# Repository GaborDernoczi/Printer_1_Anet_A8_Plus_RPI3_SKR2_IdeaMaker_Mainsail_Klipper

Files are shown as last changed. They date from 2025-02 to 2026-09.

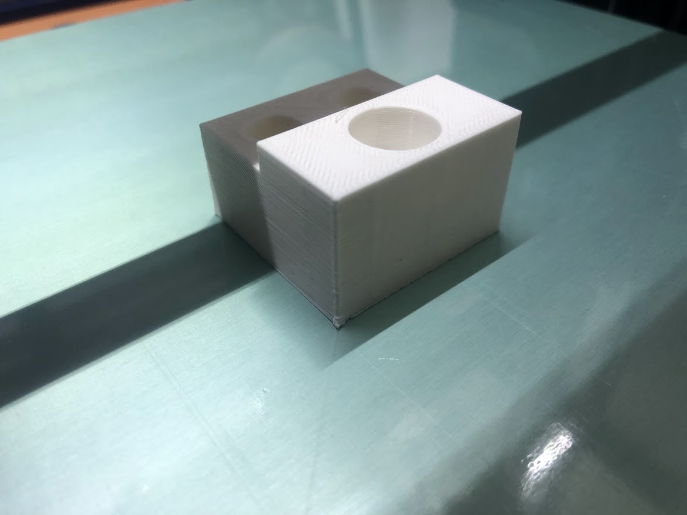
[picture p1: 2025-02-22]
Pictures/Test_Part_Print_1.jpg

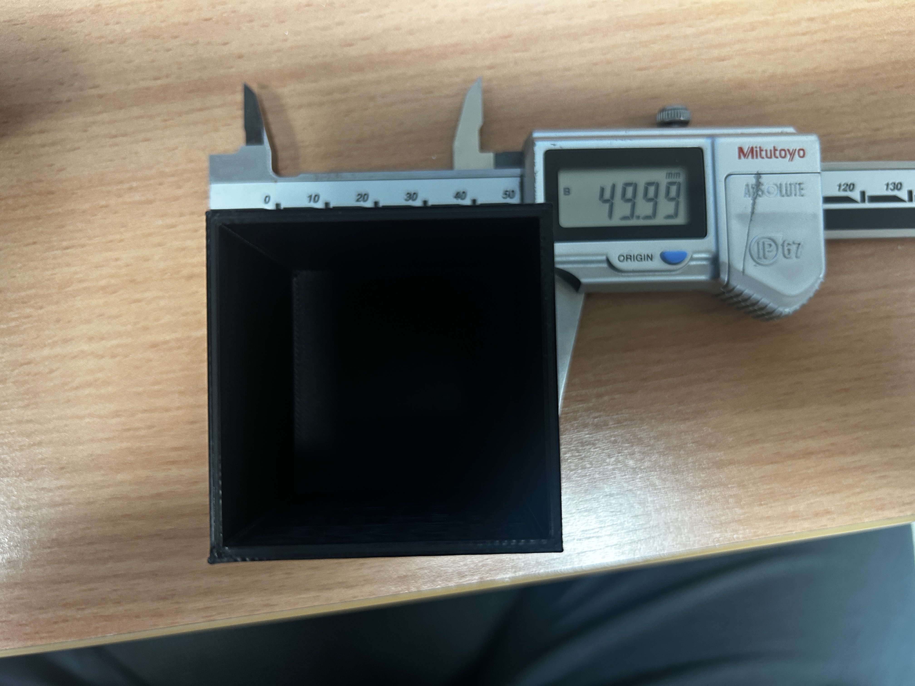
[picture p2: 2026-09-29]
Calibration_2.loop/IMG_4129.JPG

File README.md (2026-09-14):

# Printer #1 — Anet A8 Plus → Klipper / MainsailOS Conversion

> Converting an Anet A8 Plus from **Marlin + OctoPrint** to **Klipper + Mainsail**, running on a
> Raspberry Pi 3B+ with a BigTreeTech SKR 2 controller, sliced with the **latest version of
> IdeaMaker** — and fully operable remotely.

This repository is a complete build log and configuration archive. The goal is that the printer
can be **rebuilt from scratch using only the files in this repo**.

---

## Table of Contents

1. [Project Background](#1-project-background)
2. [System Architecture](#2-system-architecture)
3. [Remote Operation](#3-remote-operation)
4. [Hardware](#4-hardware)
5. [Repository Structure](#5-repository-structure)
6. [Rebuild Guide](#6-rebuild-guide)
7. [Key Configuration Values](#7-key-configuration-values)
8. [IdeaMaker Slicer Setup](#8-ideamaker-slicer-setup)
9. [Calibration Results](#9-calibration-results)
10. [Printed Upgrade Parts](#10-printed-upgrade-parts)
11. [References](#11-references)

---

## 1. Project Background

Printer #1 originally ran **Marlin firmware with OctoPrint**. It suffered from recurring problems:

- Inconsistent **bed adhesion**
- Unstable **temperature control**
- Poor and inconsistent print quality, leading to frequent failed prints
- Repeated bed-height calibration did not solve the underlying issues

Meanwhile, **Printer #2** had been running reliably for years on **Klipper + Mainsail**. Based on
that track record, the decision was made to migrate Printer #1 to the same platform.

The migration required separating the **IP addresses and Raspberry Pi hostnames** of the two
printers so both could coexist on the same network (two Raspberry Pis, two independent Mainsail
instances).

### Outcome

After the conversion the printer has been running **stably**, with no further adhesion or
temperature problems, and significantly improved print performance. Dimensional accuracy was then
dialled in through a documented calibration cycle (see section 9), and the whole workflow — from
slicing to starting the print — became operable without physically touching the machine
(see section 3).

---

## 2. System Architecture

```mermaid
flowchart LR
    PC["Workstation<br/>IdeaMaker slicer"]
    WEB["Browser<br/>Mainsail UI"]
    RPI["Raspberry Pi 3B+<br/>MainsailOS 64-bit<br/>hostname: pi1"]
    KLIPPY["Klippy host process<br/>+ Moonraker API"]
    SKR["BTT SKR 2<br/>STM32F407<br/>TMC2209 x4"]
    HW["Steppers · Heaters<br/>Thermistors · BLTouch"]

    PC -->|upload .gcode| WEB
    WEB -->|HTTP / WebSocket :7125| RPI
    RPI --- KLIPPY
    KLIPPY -->|USB serial| SKR
    SKR --> HW
```

**Division of labour:** the Raspberry Pi does all motion planning, kinematics, pressure advance
and bed-mesh compensation. The SKR 2 only executes pre-computed step timings. This is why the
Klipper configuration lives entirely in `printer.cfg` on the Pi, and the firmware on the board
almost never needs reflashing.

---

## 3. Remote Operation

A core goal of the conversion was **full remote control**: the entire chain — workstation, printer
power, slicing, print start and supervision — can be driven without being in the same room as the
machine.

```mermaid
flowchart TD
    U["Operator<br/>(remote / voice)"]
    ALEXA["Amazon Alexa"]
    SON["Sonoff 230 V smart socket"]
    NANO["Arduino Nano<br/>(powered from the socket, 5 V)"]
    REL["Relay module<br/>momentary contact closure"]
    BTN["PC front-panel<br/>PWR_SW header"]
    PCX["Workstation PC<br/>powers on"]
    PWR["Remote mains switch<br/>printer + Raspberry Pi"]
    PRN["Printer + Raspberry Pi<br/>power on"]
    SLICE["IdeaMaker<br/>slice + export G-code"]
    MS["Mainsail<br/>upload + start print"]
    CAM["Webcam via crowsnest<br/>live supervision"]

    U --> ALEXA --> SON --> NANO --> REL --> BTN --> PCX --> SLICE --> MS
    U --> PWR --> PRN --> MS
    MS --> CAM --> U
```

### Remote power-on of the workstation

The PC is **not** started with Wake-on-LAN. Instead it is started by physically pressing its own
power button, electrically:

1. The operator issues a switch-on command to **Amazon Alexa** (voice or app).
2. Alexa switches on a **Sonoff 230 V smart socket**.
3. The socket feeds an **Arduino Nano**, which therefore boots the moment mains power appears.
4. On start-up the Nano drives a **relay module**.
5. The relay **closes the contacts of the PC's power button** (the `PWR_SW` front-panel header),
   which boots the workstation.

The advantage over Wake-on-LAN is that it is completely independent of the BIOS, the network card,
the operating system and Windows fast-startup. It works even after a full power loss, because it
emulates the same physical action a person would perform.

> **Important:** the relay must produce a **short pulse (roughly 0.3–1 s), not a permanent
> closure.** A continuously held power button is interpreted by the PC as a forced shutdown
> request. The Nano sketch should therefore pulse the relay once after boot and then leave it
> open.

### What each piece does

| Capability | How | Result |
|---|---|---|
| **Start the PC remotely** | Alexa → Sonoff 230 V socket → Arduino Nano (5 V) → relay module → PC power-button contacts | The slicing machine is brought up on demand; no need to leave it running |
| **Start the printer remotely** | Remotely switchable mains power feeding the printer and the Pi | The machine stays powered down between jobs and is energised only when a print is planned |
| **Slice remotely** | Remote desktop onto the workstation, IdeaMaker running there | The slicer profile lives on one machine only — no profile drift |
| **Upload and start** | Mainsail web UI / Moonraker API on port 7125 | Upload `.gcode`, start, pause, cancel, tune live |
| **Watch the print** | `crowsnest` webcam stream embedded in Mainsail | Visual confirmation of the first layer and of progress |
| **Timelapse** | `moonraker-timelapse` (`timelapse.cfg`) | Automatic video of completed prints |

### Why the printer is kept unpowered between jobs

Leaving a heated-bed printer permanently energised is the main fire-risk scenario in a home
workshop. Putting the mains feed on a remotely switchable outlet makes the **default state "off"**,
and power is applied only for the duration of a supervised job. The Raspberry Pi boots in under a
minute, so there is no practical downside.

### Requirements and safety rules

- **Pulse, do not hold, the PC power button.** The Arduino Nano must close the relay only
  momentarily after boot; a permanently closed contact forces the PC off instead of on.
- **Use the relay contacts only as a dry switch** across the `PWR_SW` header. Never feed the
  Arduino's 5 V into the header — the relay must isolate the two circuits.
- **Set the PC BIOS "restore on AC power loss" option to "stay off"**, otherwise the machine may
  boot on its own and the relay pulse will shut it down again.
- **Give the Pi and the PC reserved DHCP leases** so their addresses never move.
- **Do not expose Mainsail or Moonraker directly to the internet.** Moonraker has no
  authentication model suitable for public exposure; `moonraker.conf` in this repo trusts private
  LAN ranges only. Reach the printer from outside over a **VPN**.
- **Never start a heater without a working camera view.** Remote power-on combined with an
  unattended thermal fault is precisely the combination to avoid.
- **Always verify the first layer on the camera** before leaving the print unattended.
- Keep a **physically reachable power cut-off**. A remote switch must never be the only way to
  de-energise the printer.

---

## 4. Hardware

| Component | Part | Notes |
|---|---|---|
| Base printer | Anet A8 Plus | 300 × 300 × 300 mm build volume |
| Frame | Reinforced aluminium-extrusion conversion | Diagonal bracing + corner gussets (AM8-style). Replaces the original acrylic frame. |
| Controller | BigTreeTech **SKR 2** | STM32F407 (verify — later batches use STM32F429) |
| Stepper drivers | **TMC2209** ×4 | UART mode |
| Host | **Raspberry Pi 3B+** | MainsailOS 64-bit |
| Hotend | **Volcano V6** | Custom mounting solution |
| Probe | **BLTouch / 3D Touch** | Automatic bed mesh levelling |
| Power | **External MOSFET** for the heated bed | Offloads bed current from the board |
| Mains control | **Remotely switchable outlet** (smart plug / relay) | Allows the printer to be powered up and down remotely — see section 3 |
| Camera | USB / Pi camera via **crowsnest** | Live view for remote supervision; timelapse support included |
| Slicer host | Workstation PC, started by the Sonoff + Arduino Nano + relay circuit | Runs the latest IdeaMaker; can be started remotely — see section 3 |
| PC remote start | **Sonoff 230 V smart socket** + **Arduino Nano** + **relay module** | Alexa-triggered; the relay shorts the PC power-button contacts |

> ⚠️ **Check your SKR 2 revision.** The initial revision of this board has a known flaw that can
> damage itself and other boards. Verify your board is not affected before powering it up.

---

## 5. Repository Structure

| Path | Contents |
|---|---|
| `Configuration_Files_Mainsail_Klipper/` | `printer.cfg`, `moonraker.conf`, `mainsail.cfg`, `crowsnest.conf`, `sonar.conf`, `timelapse.cfg` — the full working Klipper/Moonraker config set |
| `Calibration/` | Calibration log in **English** and **Hungarian**, test photos, IdeaMaker profile PDF, flow-calibration cube G-code |
| `IdeaMaker_Profiles/` | Slicer **Start G Code** and **End G Code** |
| `IdeaMaker_Models/` | `.idea` project files and `.3mf` models actually printed on this machine |
| `Consoles_and_Parts/` | STL files for printed upgrade parts (belt tensioners, fan duct, Pi case, spacers) |
| `Pictures/` | Build and diagnostic photos (BLTouch wiring, external MOSFET, printer render, test prints) |
| `SKR2_User manual/` | BigTreeTech SKR 2 pinout PDF |
| `Mainsail and Klipper Anet A8 Plus_RPI3_SKR2.pdf` | Step-by-step conversion presentation (also `.pptx`) |

---

## 6. Rebuild Guide

### Step 1 — Flash MainsailOS onto the SD card

1. Install **Raspberry Pi Imager**.
2. Choose **Other specific-purpose OS → 3D printing → MainsailOS (64-bit)**.
3. In the Imager's advanced settings, configure **before** writing:
   - **Hostname** — must be unique per printer (this build uses `pi1`)
   - **Wi-Fi SSID + password**
   - **SSH enabled**, username and password
4. Write the image and boot the Pi.

> **Running two printers?** Give each Pi a distinct hostname *and* a reserved (static) DHCP lease
> in the router. Two Pis = two independent Mainsail instances. Mixing them up is the most common
> cause of "I edited the config and nothing changed".

### Step 2 — Build the Klipper firmware for the SKR 2

SSH into the Pi (e.g. with **Tera Term** or any SSH client) and run:

```bash
cd ~/klipper
make menuconfig
```

Select:

| Option | Value |
|---|---|
| Micro-controller Architecture | `STMicroelectronics STM32` |
| Processor model | `STM32F407` *(use `STM32F429` if that is the chip on your board)* |
| Bootloader offset | `32KiB bootloader` |
| Communication interface | `USB (on PA11/PA12)` |

Then build:

```bash
make clean
make
```

The output is `~/klipper/out/klipper.bin`.

### Step 3 — Flash the board

`make flash` **does not work** on the SKR 2. Flash via SD card instead:

1. Download `out/klipper.bin` from the Pi (e.g. with **FileZilla** over SFTP).
2. Rename it to **`firmware.bin`**.
3. Copy it to a FAT32 SD card and insert it into the SKR 2.
4. Make sure the SKR 2 **power-source jumper is set correctly (5 V mode)**.
5. Power-cycle the board.
6. **Verification:** the file on the SD card is renamed to `firmware.cur`. If it still says
   `firmware.bin`, the flash did not happen — check the card format, the filename and the jumper.

### Step 4 — Find the MCU serial ID

On the Pi:

```bash
ls /dev/serial/by-id/*
```

Copy the returned path into the `[mcu]` section of `printer.cfg`. Example from this build:

```ini
[mcu]
serial: /dev/serial/by-id/usb-Klipper_stm32f407xx_2D0027000C47393437303337-if00
```

> This ID is **unique to your board** — it will not match the value in this repo. You must
> replace it.

### Step 5 — Upload the configuration

Copy `Configuration_Files_Mainsail_Klipper/printer.cfg` to the Pi, either through the Mainsail
web UI (**Machine** tab) or over SFTP to `~/printer_data/config/`.

Then check `moonraker.conf` — the `[authorization] trusted_clients` list must include your LAN
subnet, otherwise the web UI will refuse the connection.

Restart Klipper from Mainsail (`FIRMWARE_RESTART`).

### Step 6 — Wire and enable the BLTouch

Wiring photos: `Pictures/3d_touch.jpg`, `3d_touch_2.jpg`, `3d_touch_pins.jpg`.

The probe replaces the Z endstop — note that `[stepper_z]` uses
`endstop_pin: probe:z_virtual_endstop`.

### Step 7 — Safety checks before the first print

Run these **in order**, and keep a hand on the power switch:

```gcode
# 1. Thermistors read plausible room temperature?      -> check Mainsail dashboard
# 2. Does the probe deploy/stow?
BLTOUCH_DEBUG COMMAND=pin_down
BLTOUCH_DEBUG COMMAND=pin_up
# 3. Do the axes move the RIGHT way and hit the endstops?
G28
# 4. PID tuning
PID_CALIBRATE HEATER=extruder TARGET=200
PID_CALIBRATE HEATER=heater_bed TARGET=60
SAVE_CONFIG
# 5. Probe Z offset
PROBE_CALIBRATE
SAVE_CONFIG
# 6. Bed mesh
G28
BED_MESH_CALIBRATE
SAVE_CONFIG
```

> `SAVE_CONFIG` **restarts Klipper** — that is normal. It writes results into the auto-generated
> block at the bottom of `printer.cfg`, which **overrides** the values at the top of the file.

### Step 8 — Calibrate the extruder

Mark 120 mm of filament, then extrude 100 mm and measure what is left. `printer.cfg` already
contains `max_extrude_only_distance: 150` specifically to allow the 100 mm test (the Klipper
default of 50 mm is too small).

---

## 7. Key Configuration Values

From `Configuration_Files_Mainsail_Klipper/printer.cfg`:

### Motion

| Setting | Value | Why |
|---|---|---|
| `kinematics` | `cartesian` | |
| `stepper_x` / `stepper_y` `rotation_distance` | **40** | Theoretical value for a 16-tooth GT2 pulley — **do not change** |
| `stepper_z` `rotation_distance` | **8** | TR8×8 lead screw, mathematically exact — **never change** |
| `microsteps` | 16 (all axes) | |
| `position_max` X / Y / Z | 300 / 300 / 300 | |
| `max_velocity` | 300 mm/s | |
| `max_accel` | **1500** mm/s² | Reduced from 3000 to suppress ringing and corner defects |
| `square_corner_velocity` | 5.0 | |
| `max_z_velocity` / `max_z_accel` | 5 / 100 | |

### Extruder

| Setting | Value |
|---|---|
| `rotation_distance` | 35.845 (calibrated) |
| `nozzle_diameter` | 0.400 mm |
| `sensor_type` | EPCOS 100K B57560G104F |
| `max_temp` | 250 °C |
| `max_extrude_only_distance` | 150 mm |
| `pressure_advance` | 0.05 |
| `pressure_advance_smooth_time` | 0.040 |
| TMC2209 `run_current` | 0.600 A |

### Bed & Probe

| Setting | Value |
|---|---|
| `heater_bed` `sensor_type` | Generic 3950 |
| BLTouch `x_offset` / `y_offset` | **−30 / −25** |
| BLTouch `z_offset` | 1.25 |
| `samples` / `samples_result` | 2 / average |
| `safe_z_home` `home_xy_position` | 150, 150 (bed centre) |
| `bed_mesh` area | 35,30 → 280,280 |
| `bed_mesh` `probe_count` | 5 × 5, bicubic |
| XY/Z TMC2209 `run_current` | 0.800 A |

### SKR 2 specifics

```ini
# BTT implements a Marlin-specific "anti-reversal stepper protection".
# This pin MUST be pulled high or the stepper drivers and most FETs get no power.
[output_pin motor_power]
pin: PC13
value: 1
```

Forgetting this block is the classic "motors do nothing and there is no error message" failure on
the SKR 2.

---

## 8. IdeaMaker Slicer Setup

The slicer belonging to this printer is **IdeaMaker, latest version** (Raise3D). It is free, and
the profile stored in this repository is maintained against the current release — download it from
<https://www.raise3d.com/ideamaker/>.

Copy the contents of `IdeaMaker_Profiles/` into the printer definition in IdeaMaker.

**Start G-code** — homes all axes, moves to a bed-edge reference point, sets the coordinate zero
and performs a slow Z touch-off before lifting and priming.

**End G-code** — turns off both heaters, retracts in two stages while lifting Z, and disables the
steppers.

**Acceleration and Jerk are deliberately disabled in the slicer.** Klipper handles motion planning
itself, and letting the slicer inject `M204`/`M205` would fight the `max_accel` and
`square_corner_velocity` settings in `printer.cfg`.

The full profile is documented as screenshots in
`Calibration/Printer1_ANET_A8_Plus_RPI3_SKR2_Ideamaker_Current_Profile.pdf`.

---

## 9. Calibration Results

Test object: **50 × 50 × 50 mm** calibration cube. Full narrative in
[Calibration/Calibration_log_EN.txt](Calibration/Calibration_log_EN.txt) (Hungarian version:
[Kalibracios_naplo_HU.txt](Calibration/Kalibracios_naplo_HU.txt)).

| Test | X (mm) | Y (mm) | Z (mm) | Key settings |
|---|---|---|---|---|
| #1 | 48.63 (−1.37) | 49.76 (−0.24) | 50.21 (+0.21) | X rot.dist 40.9, z_offset 1.15, no PA, accel 3000 |
| #2 | 49.74 (−0.26) | 49.79 (−0.21) | 50.17 (+0.17) | X rot.dist **40** (fixed), PA 0.05, accel 1500 |
| #3 | **49.94** (−0.06) | **49.97** (−0.03) | **50.06** (+0.06) | z_offset 1.25 |

All three axes are now within **0.1 mm** (≈0.1 %).

### Lessons recorded

- **The X error was not mechanical.** A −2.74 % deviation looked like a loose belt, but solving
  `measured = 50 × RD_actual / RD_configured` for both axes gave nearly identical results
  (39.78 vs 39.81), proving the fault was the mistyped `rotation_distance` of 40.9.
- **Z height error does not come from `rotation_distance`.** With a TR8×8 screw the value 8 is
  exact. From the second layer onward every layer is correct — *all* height error is created in
  the **first layer**. The fix is always the probe `z_offset`.
- **Klipper sign rule:** a *larger* `z_offset` = nozzle *closer* to the bed = more squish =
  *shorter* part.
- **`SAVE_CONFIG` wins.** Once it has run, the value at the top of `printer.cfg` is ignored. To
  edit manually you must first delete the corresponding lines from the `#*#` block, then run
  `FIRMWARE_RESTART`.
- **A Z value below −4 shown in Mainsail is the head *position*, not the offset.** The dashboard
  live-adjust field and the `PROBE_CALIBRATE` panel are two different things. If you see this
  before a move — stop.

---

## 10. Printed Upgrade Parts

STLs in `Consoles_and_Parts/`:

| File | Purpose |
|---|---|
| `belt_tensioner_A2.stl`, `belt_tensioner_B2.stl` | Belt tensioners (see `belt_tensioner.png`, `beltA2.png`, `beltB2.png`) |
| `Fan_Nozzle_V2.stl` | Part-cooling fan duct |
| `Spacer_for_extruder_part.stl` | Extruder mounting spacer |
| `anet_tavtarto_63mm.stl` | 63 mm Anet spacer |
| `Rpi_4_Case_Bottom.stl` / `_Top.stl` | Raspberry Pi enclosure (plus HDMI-cable variants) |

---

## 11. References

- Klipper documentation — <https://www.klipper3d.org/>
- Pressure Advance tuning — <https://www.klipper3d.org/Pressure_Advance.html>
- Mainsail — <https://docs.mainsail.xyz/>
- MainsailOS — <https://docs.mainsail.xyz/setup/mainsail-os>
- SKR 2 pinout — `SKR2_User manual/BIGTREETECH SKR 2-Pin.pdf`
- Conversion presentation — `Mainsail and Klipper Anet A8 Plus_RPI3_SKR2.pdf`

### Tools used

| Tool | Role |
|---|---|
| Raspberry Pi Imager | Write MainsailOS to SD |
| FileZilla | SFTP transfer of `klipper.bin` and `printer.cfg` |
| Tera Term | SSH session to the Pi |
| **IdeaMaker (latest version)** | Slicer |
| Mainsail | Web interface and remote print control |
| Alexa + Sonoff 230 V socket | Remote power-on of the workstation (via Arduino Nano + relay) |
| Arduino IDE | Sketch for the Nano that pulses the relay on boot |
| Remote mains switch | Remote power-on of the printer |

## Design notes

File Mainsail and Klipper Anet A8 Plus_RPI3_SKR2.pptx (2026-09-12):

## Upgrading Anet A8 Plus to Klipper with MainsailOS Printer #1 with RPI3B+ & SKR2

Originally, Printer #1 was operating with Marlin firmware and OctoPrint. However, it frequently encountered issues with adhesion and temperature, which resulted in inconsistent and poor print quality. These issues often led to failed prints, and while the bed height calibration was regularly adjusted, this did not resolve the majority of the problems. The recurring issues were significantly impacting the overall reliability of the printer.
In contrast, Printer #2 had been operating smoothly and reliably for several years, using Klipper firmware paired with the Mainsail interface. Given the stability of Printer #2, it was decided to migrate Printer #1 to the same platform. After carefully separating the IP addresses and Raspberry Pi system names for both printers, Printer #1 was successfully transitioned to the Klipper-Mainsail setup. Following the migration, Printer #1 has been operating stably, showing no further issues with adhesion or temperature, and its performance has improved significantly.

Printer #2

Printer #1

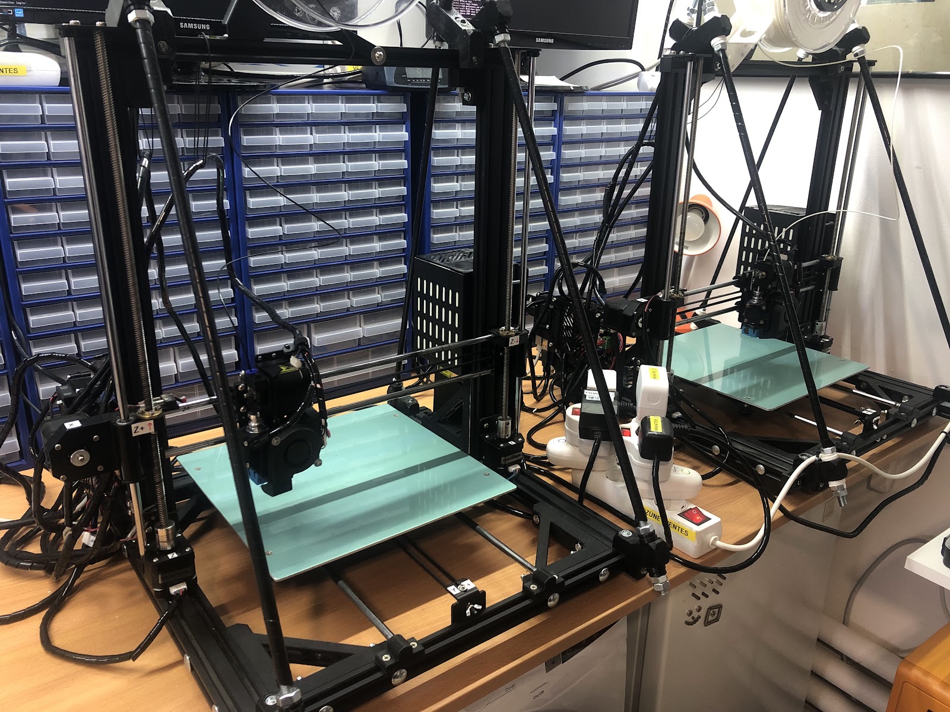
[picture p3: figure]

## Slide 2

Upgrading Anet A8 Plus to Klipper with MainsailOS
Printer #1 with RPI3B+ & SKR2

Installation of MainsailOS on Raspberry 3B+ with raspberry imager, SD card needed.
->Other spec OS Mainsail 64 bit
Set wifi and password, hostname
Configuring Multiple 3D Printers on Mainsail? Raspberry Pi x2 and Mainsail x2 (https://www.youtube.com/watch?v=sSB-l3RX6BQ)

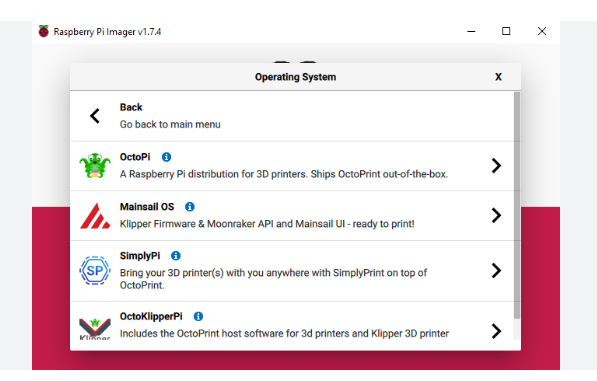
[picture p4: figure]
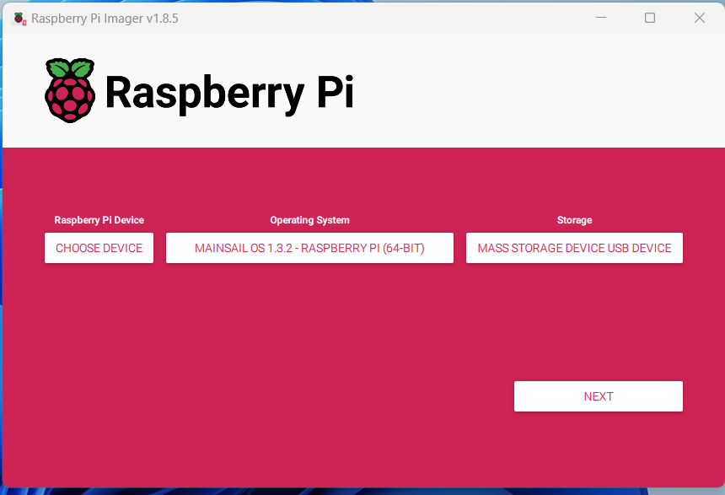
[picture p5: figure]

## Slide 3

Upgrading Anet A8 Plus to Klipper with MainsailOS
Printer #1 with RPI3B+ & SKR2

Set wifi and password, hostname
Configuring Multiple 3D Printers on Mainsail? Raspberry Pi x2 and Mainsail x2 (https://www.youtube.com/watch?v=sSB-l3RX6BQ)

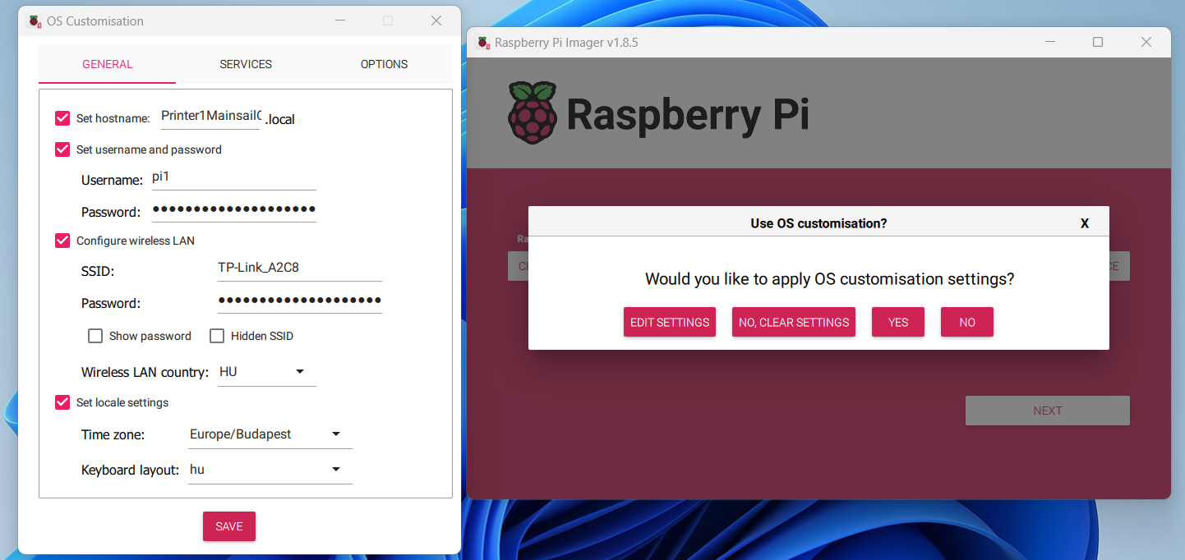
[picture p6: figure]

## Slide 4

Upgrading Anet A8 Plus to Klipper with MainsailOS
Printer #1 with RPI3B+ & SKR2

Login to Raspberry 3B+ with pi1 and password
cd klipper
make menuconfig

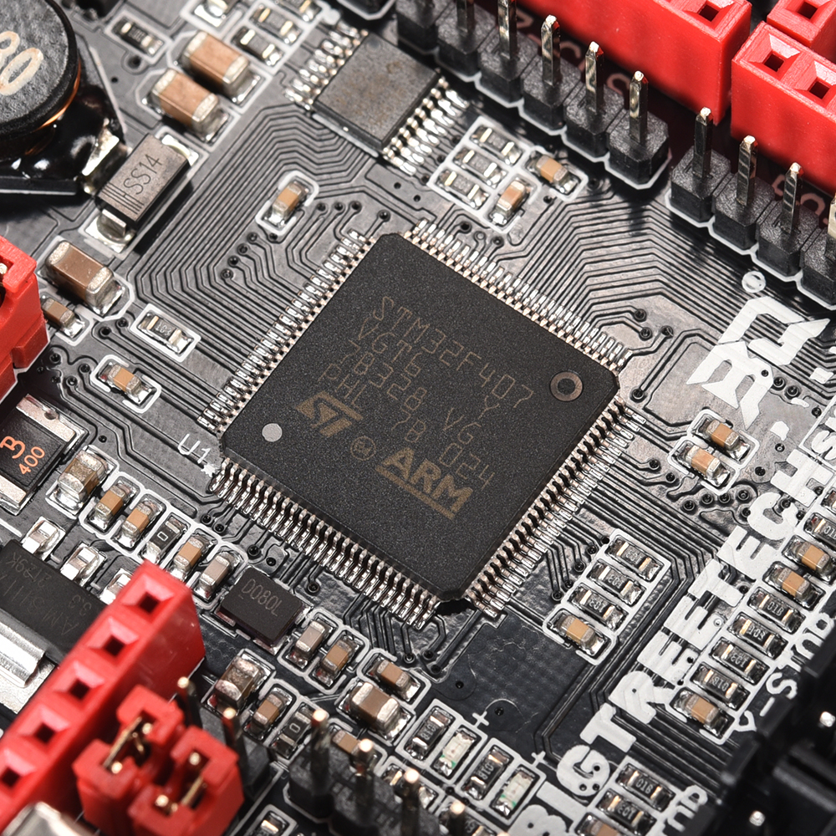
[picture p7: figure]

Make -> klipper.bin file -> SKR2

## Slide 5

Upgrading Anet A8 Plus to Klipper with MainsailOS
Printer #1 with RPI3B+ & SKR2

Download FileZilla and connect to Raspberry 3B+
Rename Klipper.bin to firmware.bin and copy to SD card ->power on SKR2
Get firmware.cur if FW update is OK (SKR2 jumper need to be set to 5v mode of course)

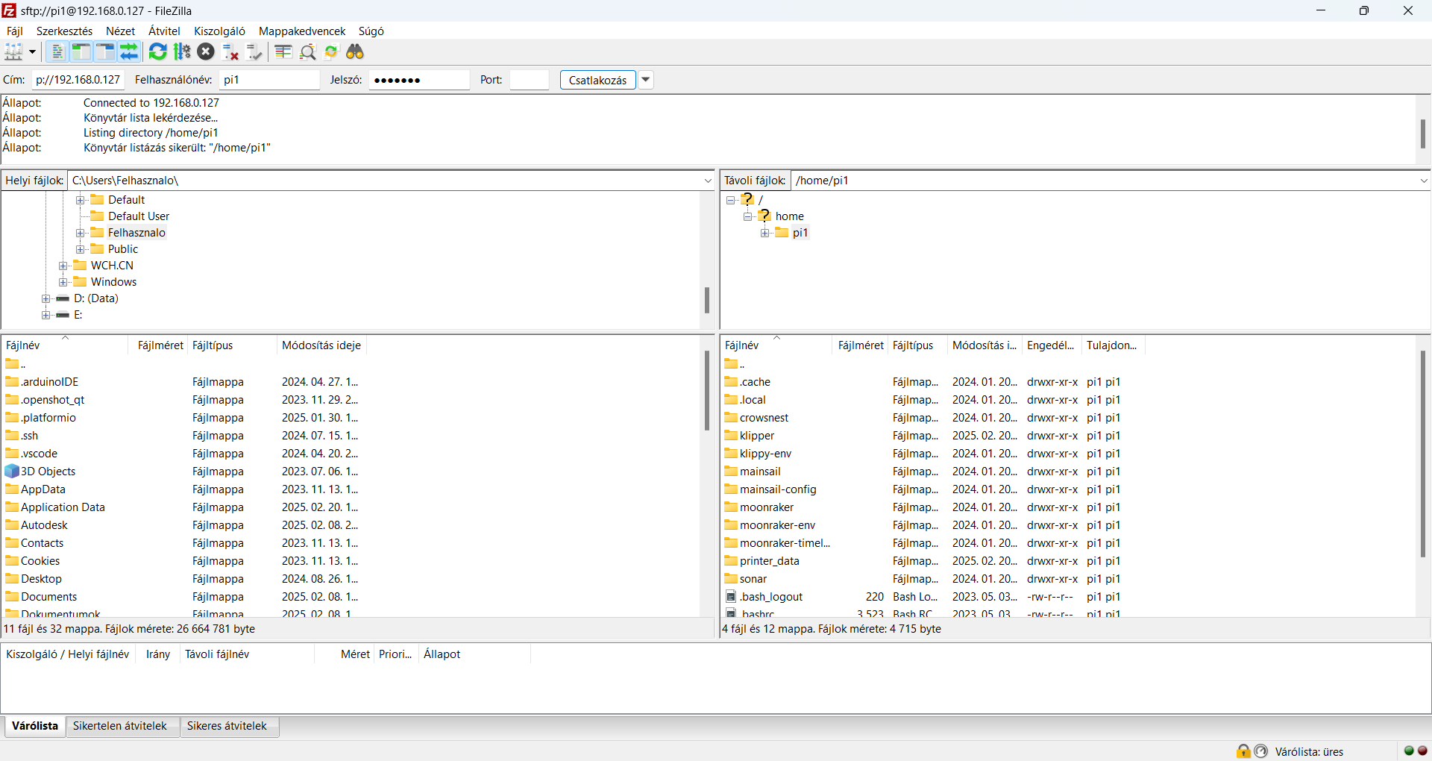
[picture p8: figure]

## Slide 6

Upgrading Anet A8 Plus to Klipper with MainsailOS
Printer #1 with RPI3B+ & SKR2

FileZilla - Copy printer.cfg and upload to Mainsail

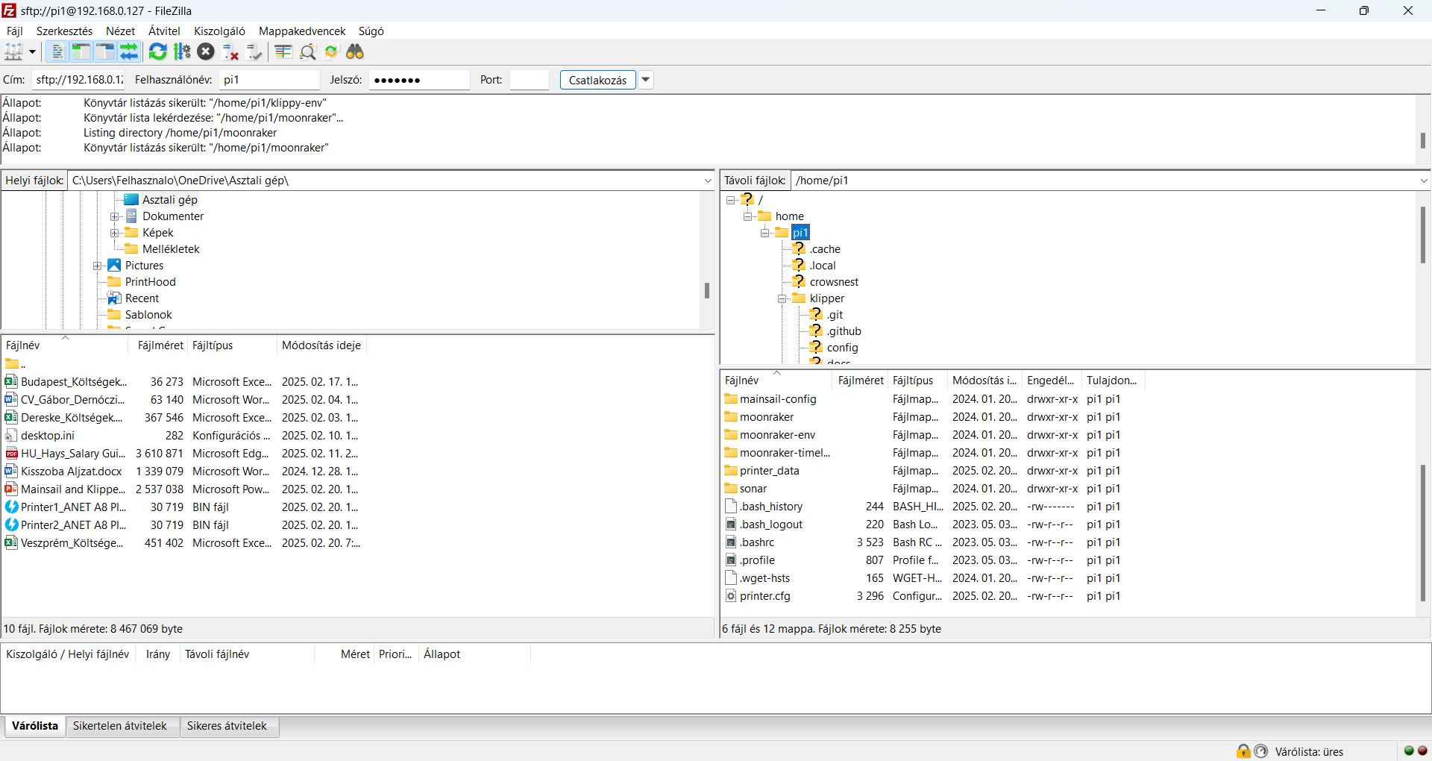
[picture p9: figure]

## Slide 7

Upgrading Anet A8 Plus to Klipper with MainsailOS
Printer #1 with RPI3B+ & SKR2

Copy printer.cfg and upload to Mainsail

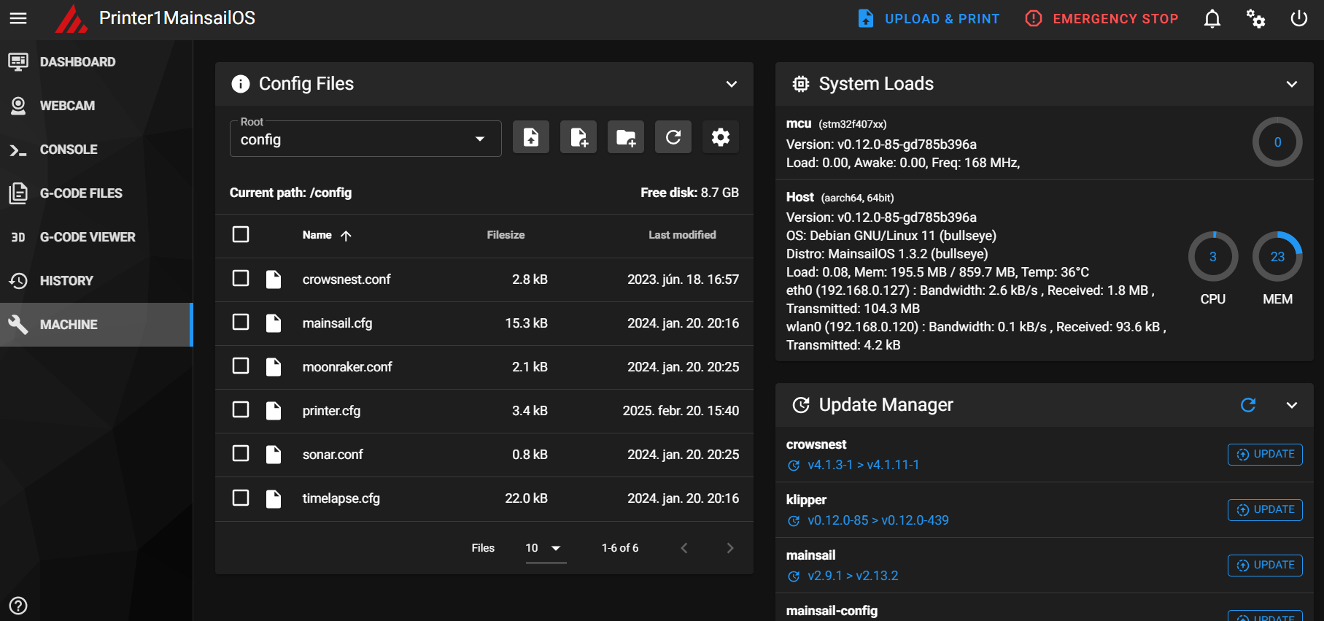
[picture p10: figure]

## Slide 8

Upgrading Anet A8 Plus to Klipper with MainsailOS
Printer #1 with RPI3B+ & SKR2

Download Tera Term and -> host -> 192.168.0.127 -> pi1 and password
Get USB ID: ls /dev/serial/by-id/*

Release Tera Term 5.3 · (https://github.com/TeraTermProject/teraterm/releases/tag/v5.3)TeraTermProject (https://github.com/TeraTermProject/teraterm/releases/tag/v5.3)/ (https://github.com/TeraTermProject/teraterm/releases/tag/v5.3)teraterm (https://github.com/TeraTermProject/teraterm/releases/tag/v5.3)

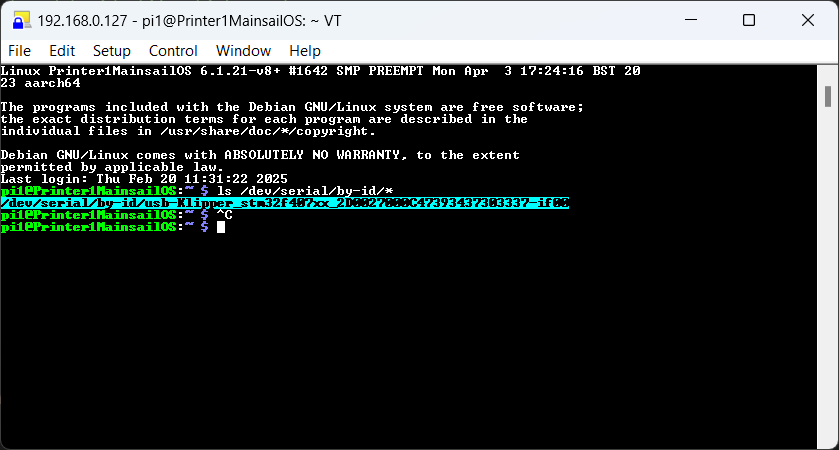
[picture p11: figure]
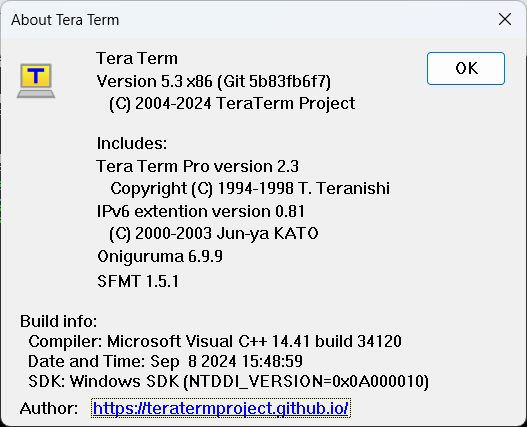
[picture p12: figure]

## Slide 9

Upgrading Anet A8 Plus to Klipper with MainsailOS
Printer #1 with RPI3B+ & SKR2

Copy USB address into printer.cfg

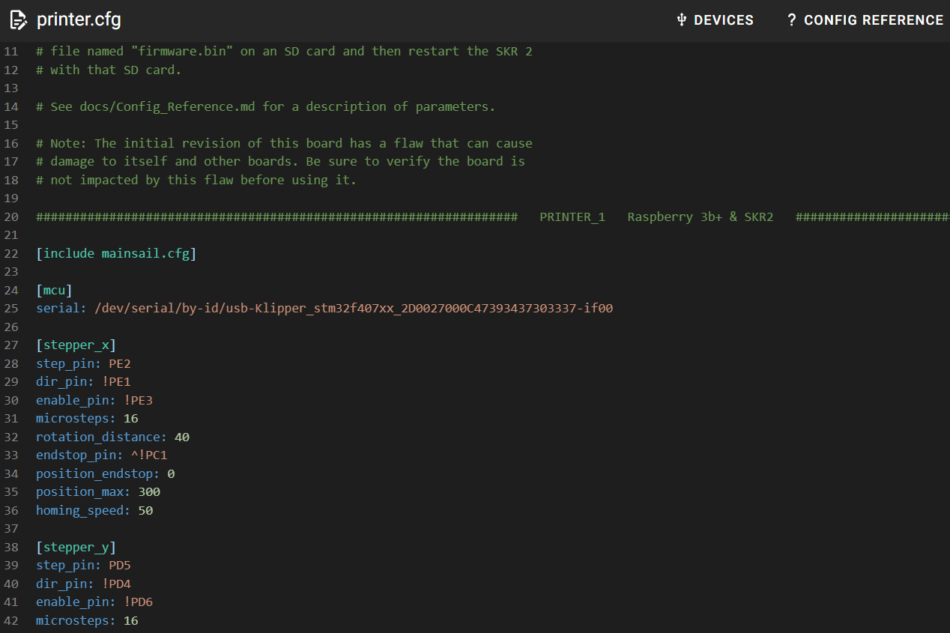
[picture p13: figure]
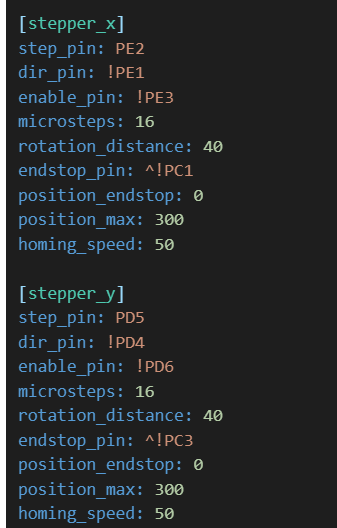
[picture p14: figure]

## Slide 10

Upgrading Anet A8 Plus to Klipper with MainsailOS
Printer #1 with RPI3B+ & SKR2

Enable TMC2209 and set Z microsteps to 16 in printer.cfg

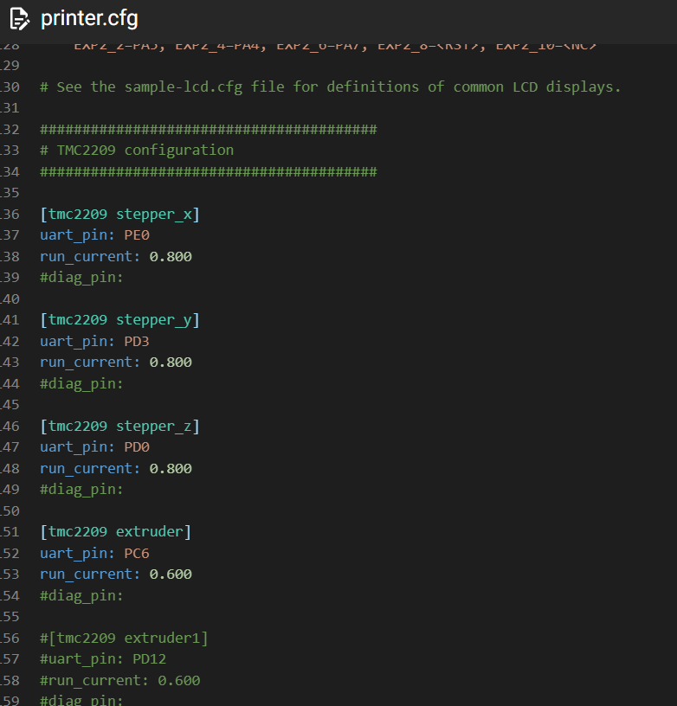
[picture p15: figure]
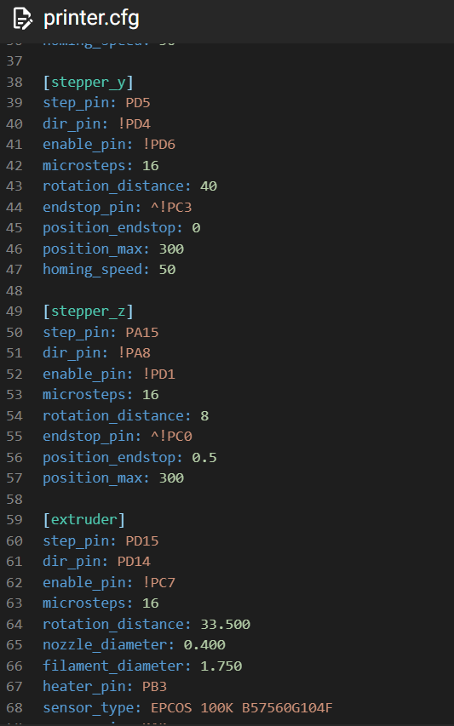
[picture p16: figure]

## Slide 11

Upgrading Anet A8 Plus to Klipper with MainsailOS
Printer #1 with RPI3B+ & SKR2

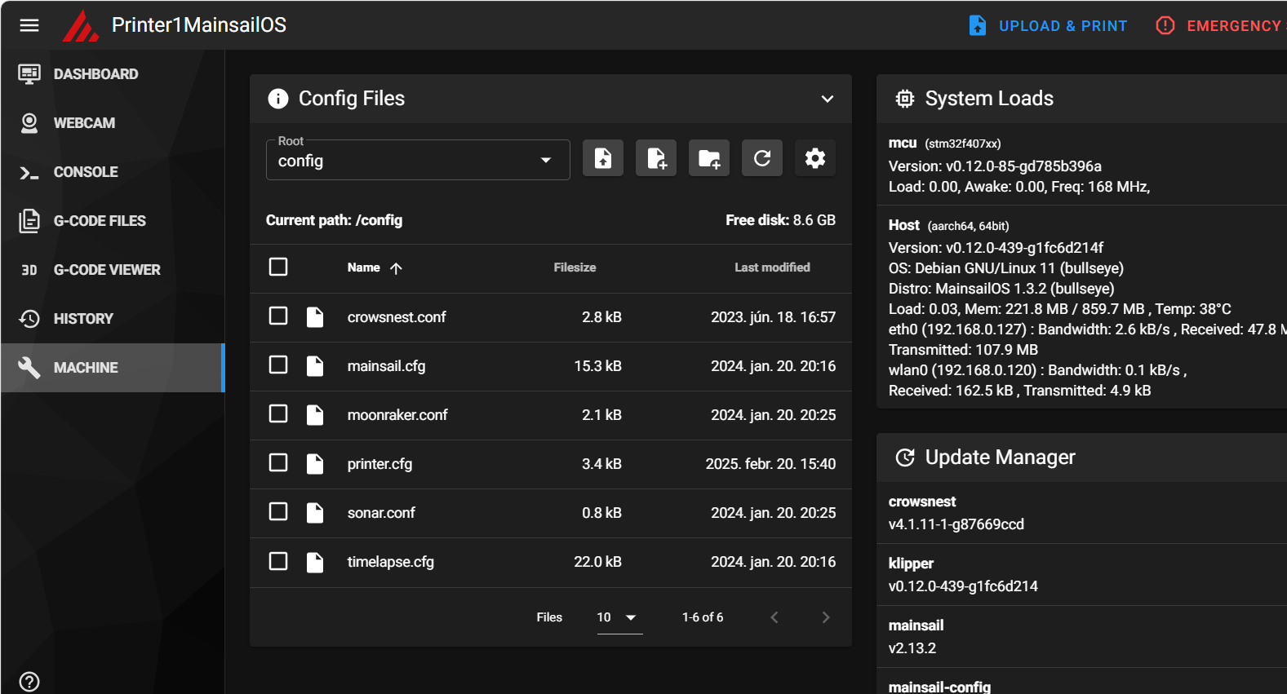
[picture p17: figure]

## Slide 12

Upgrading Anet A8 Plus to Klipper with MainsailOS
Printer #1 with RPI3B+ & SKR2

Router status

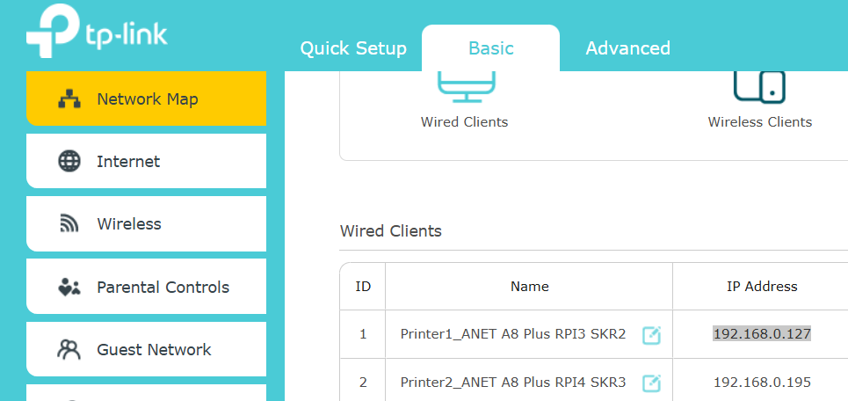
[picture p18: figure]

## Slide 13

IdeaMaker Profile

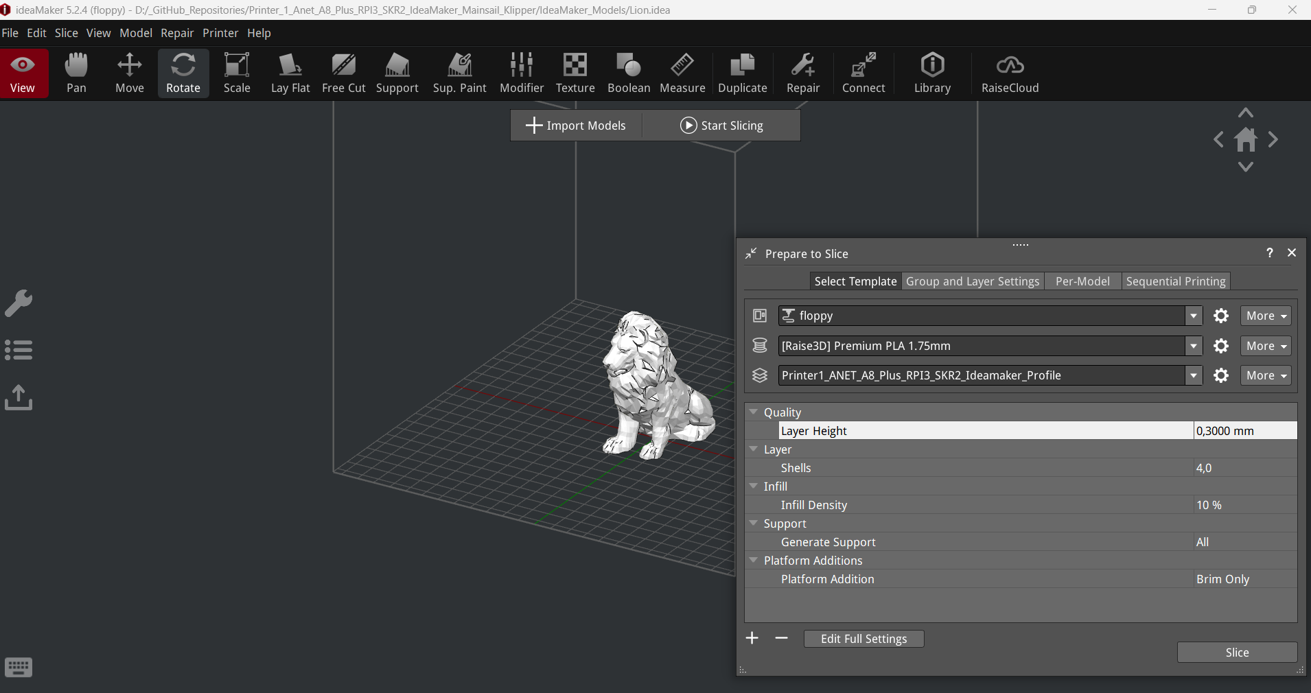
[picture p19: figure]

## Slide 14

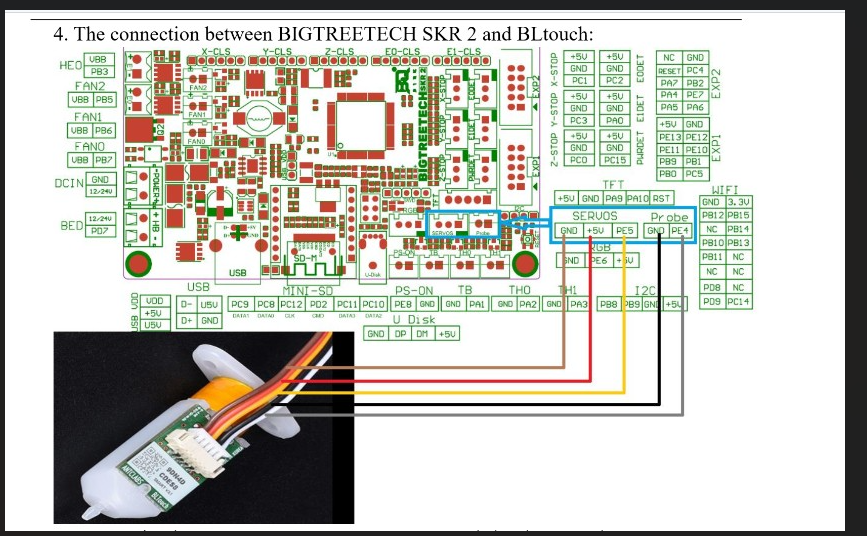
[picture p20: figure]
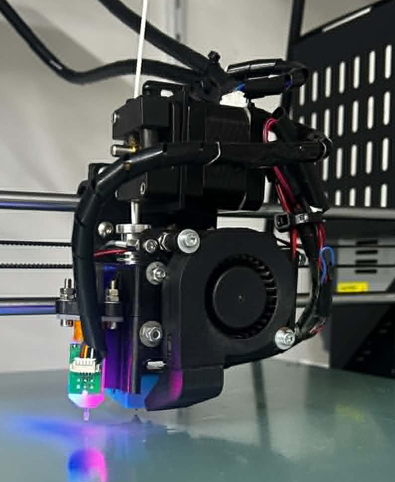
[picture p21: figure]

Upgrading Anet A8 Plus to Klipper with MainsailOS
Printer #1 with RPI3B+ & SKR2 & 3d touch

Individual solution of Volcano V6 Extruder

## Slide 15

Upgrading Anet A8 Plus to Klipper with MainsailOS
Printer #1 with RPI3B+ & SKR2

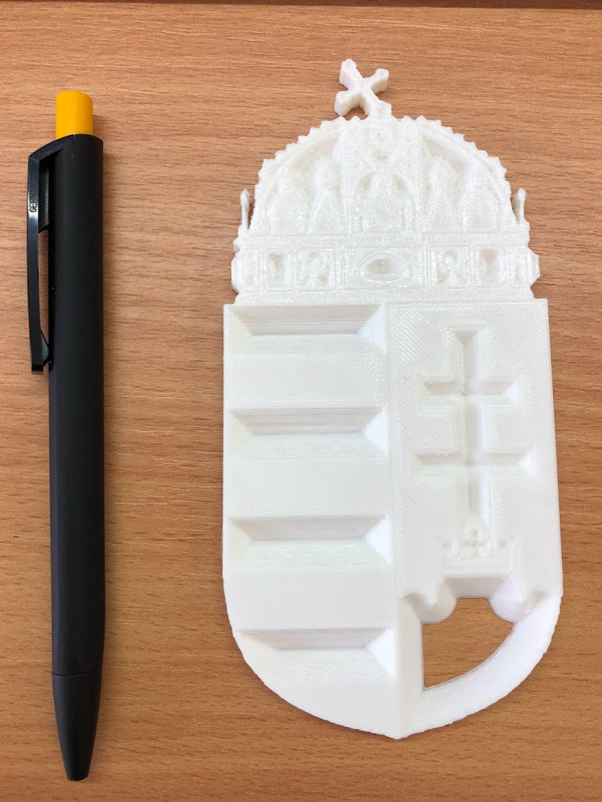
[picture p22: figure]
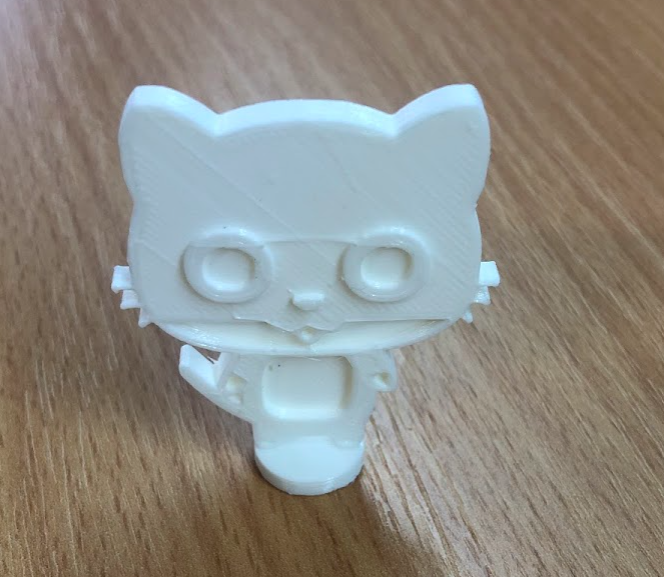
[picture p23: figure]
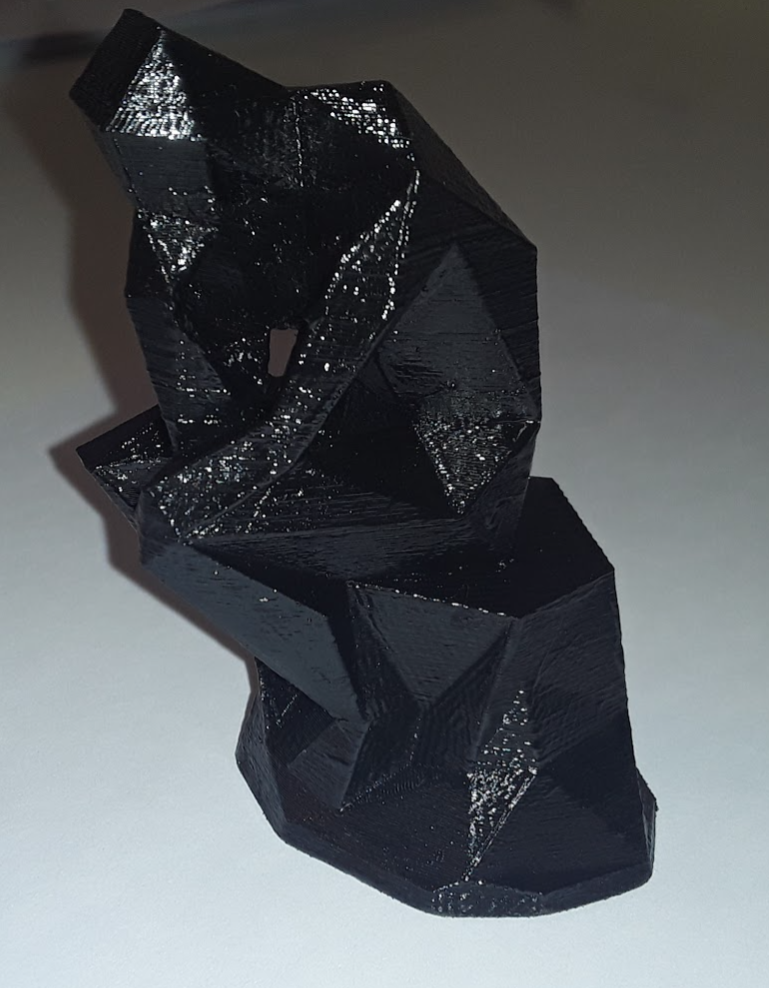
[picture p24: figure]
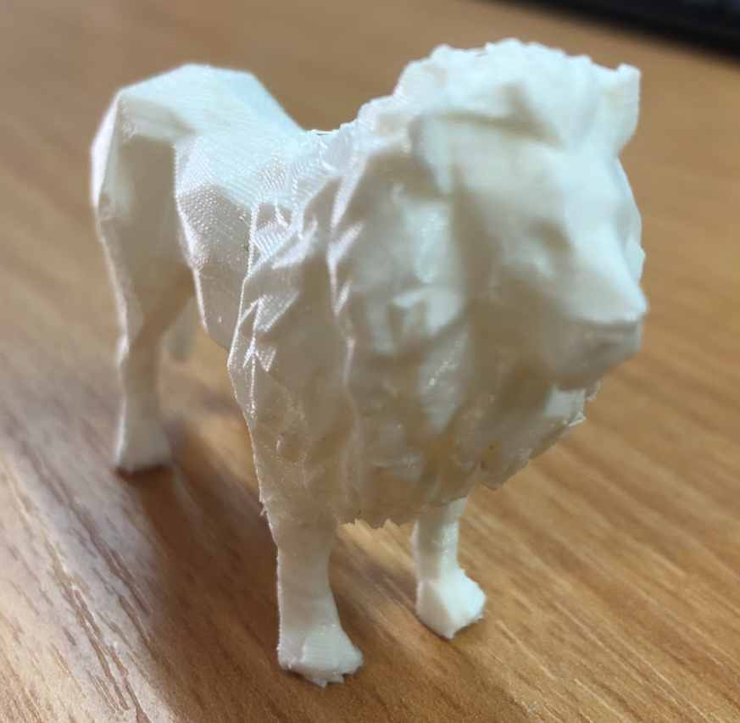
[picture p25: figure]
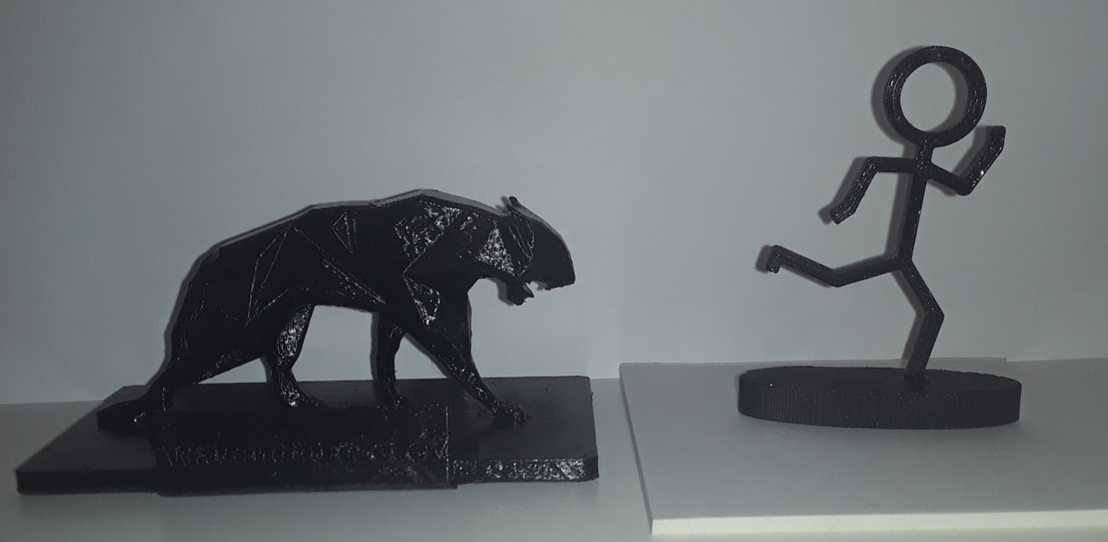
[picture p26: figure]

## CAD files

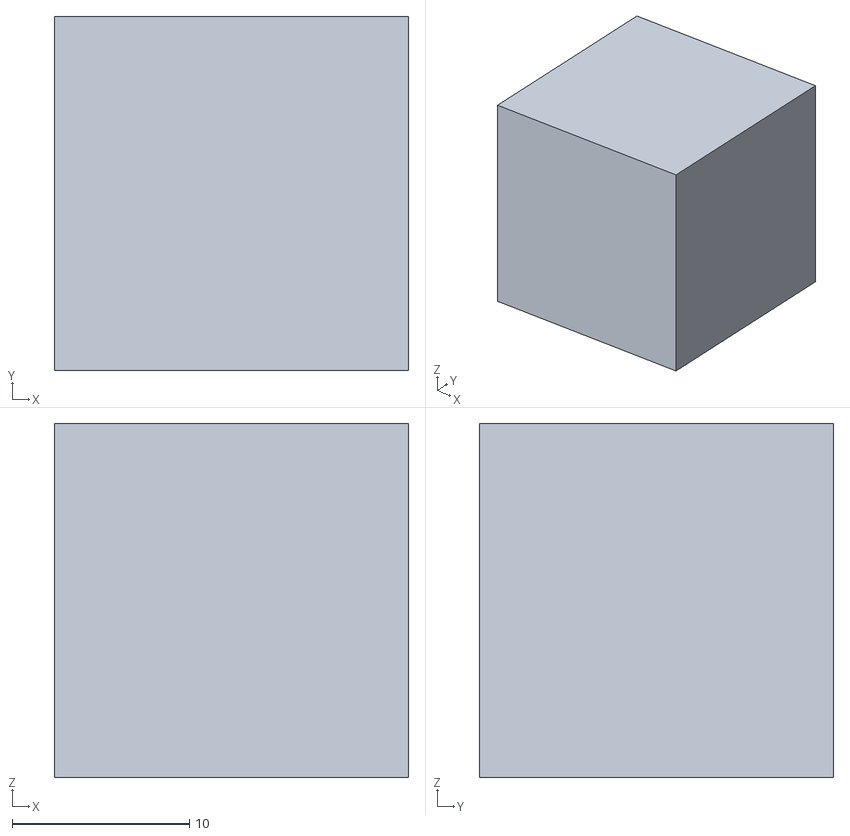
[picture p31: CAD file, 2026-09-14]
Calibration_1.loop/Calibration_hollow_cube.stl
20.0 x 20.0 x 20.0

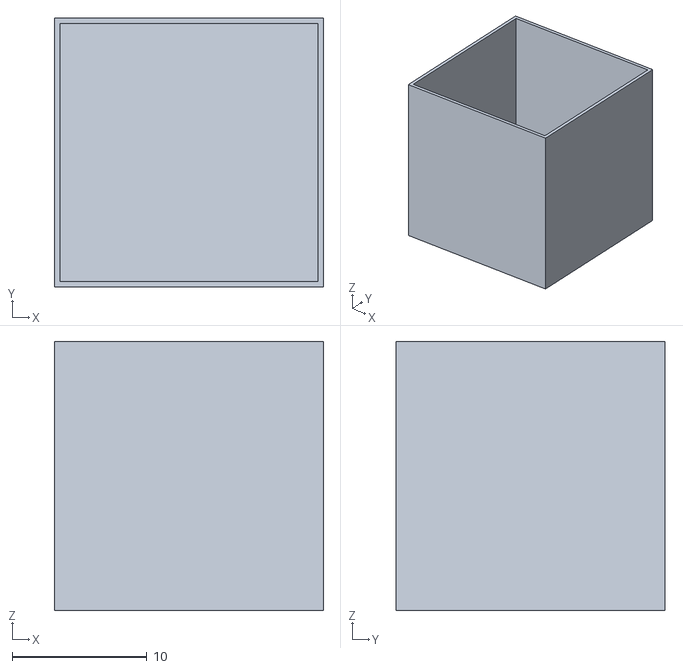
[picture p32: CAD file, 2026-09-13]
Calibration_1.loop/Flow Calibration Cube/0.20mm-nozzle-0.40mm-walls-humebeam-flow-calibration-cube.stl
20.0 x 20.0 x 20.0

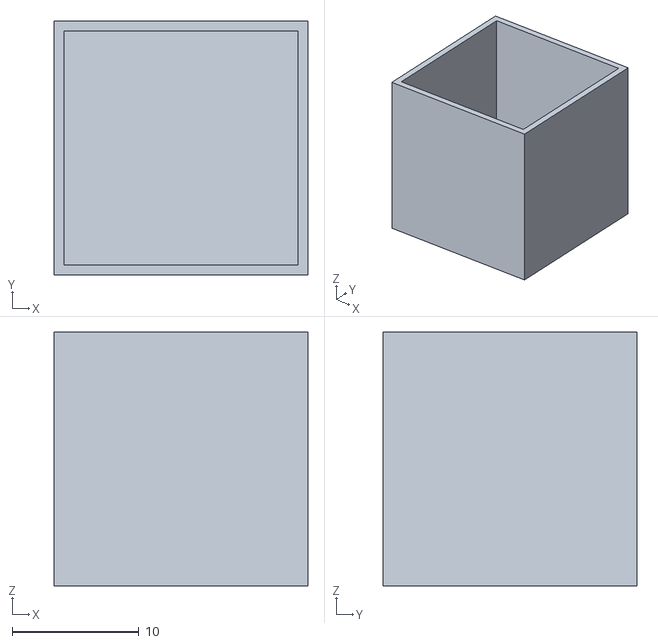
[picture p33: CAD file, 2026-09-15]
Calibration_2.loop/Flow_Calibration_Cube_0.4_mm.stl
20.0 x 20.0 x 20.0

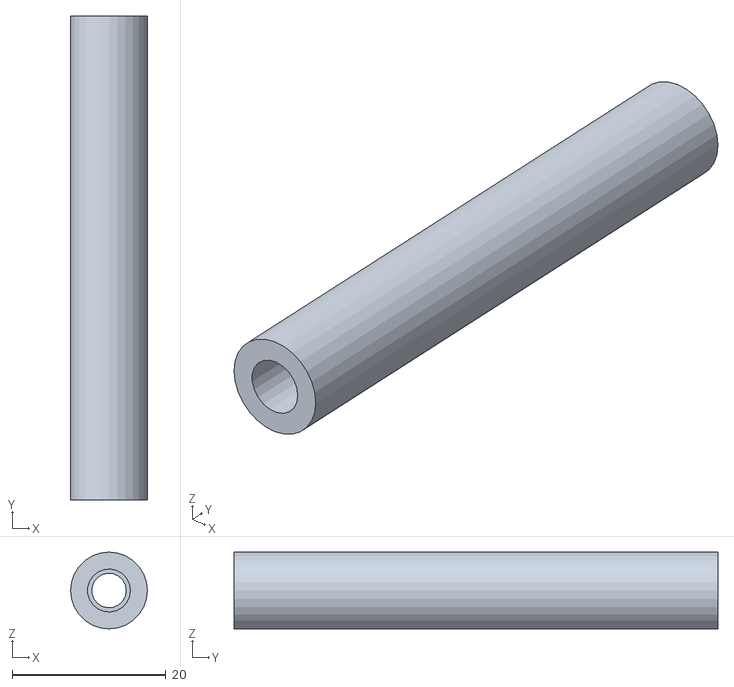
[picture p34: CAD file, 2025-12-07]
Consoles_and_Parts/anet_tavtarto_63mm.stl
10.0 x 63.0 x 10.0

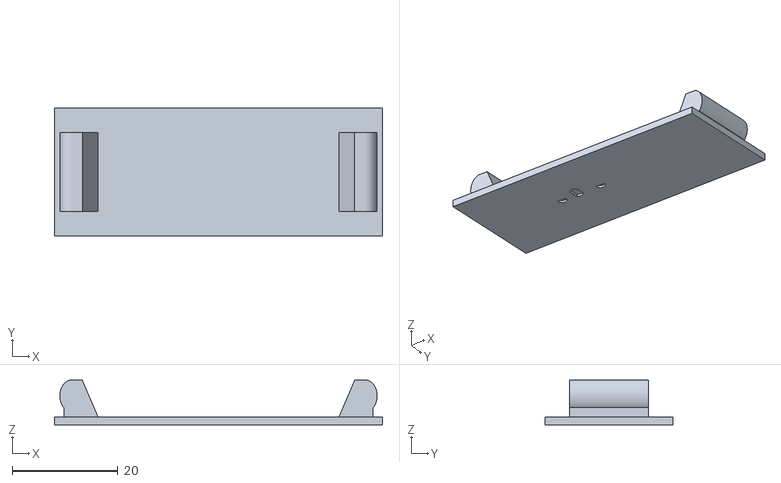
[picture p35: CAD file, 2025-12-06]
IdeaMaker_Models/Breaker_Filler_Plate_-_Schneider_-_1-UP.stl
62.0 x 24.2 x 8.50

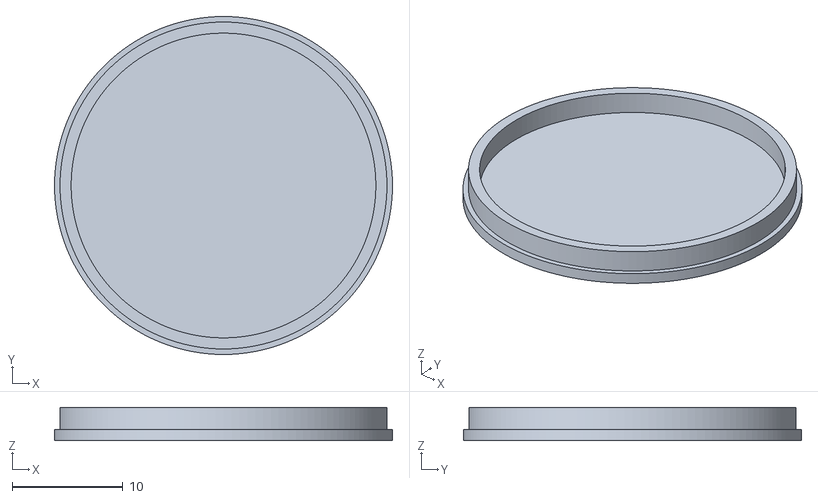
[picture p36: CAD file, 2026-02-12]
IdeaMaker_Models/Dani/hole_cap_mid_29.5.STL
30.5 x 30.5 x 3.00

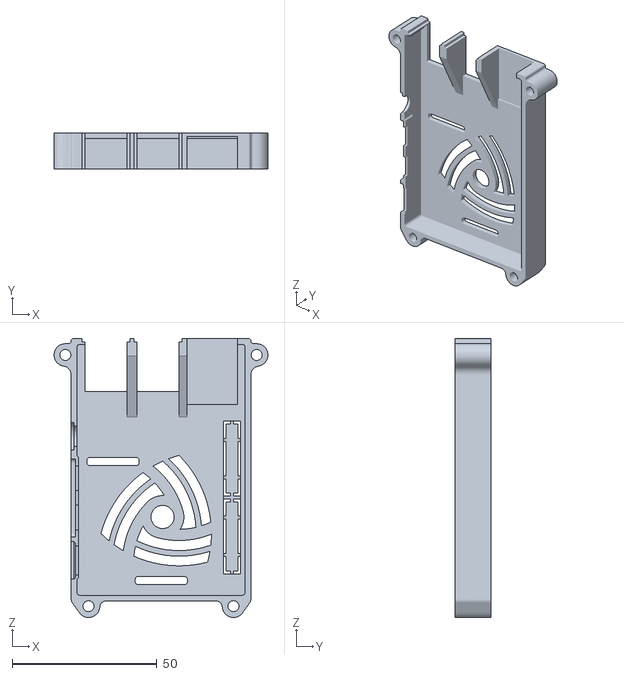
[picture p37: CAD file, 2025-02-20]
Consoles_and_Parts/Rpi_4_Case_Top_official_rPI_HDMI_cable.stl
73.8 x 12.5 x 96.2

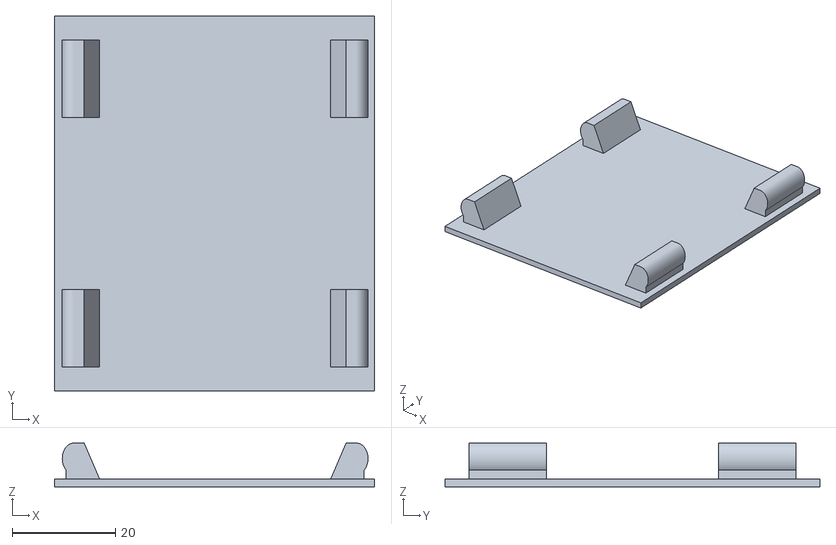
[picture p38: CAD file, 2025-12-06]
IdeaMaker_Models/Breaker_Filler_Plate_-_Thomas__Betts_-_3-UP.stl
62.0 x 72.6 x 8.50

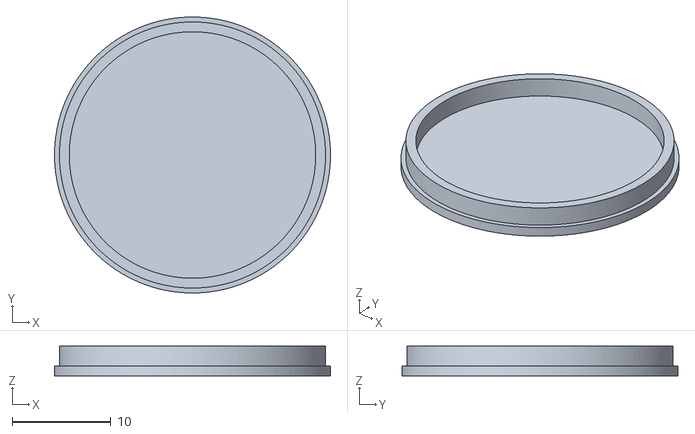
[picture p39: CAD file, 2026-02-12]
IdeaMaker_Models/Dani/hole_cap_mid_27.STL
28.0 x 28.0 x 3.00

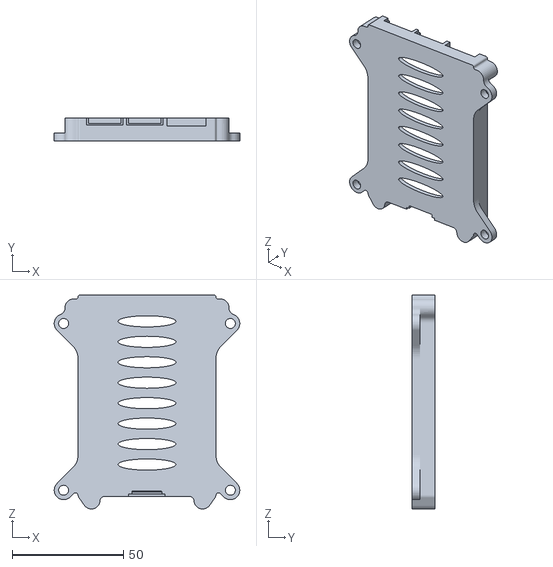
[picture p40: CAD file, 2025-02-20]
Consoles_and_Parts/Rpi_4_Case_Bottom_official_rPI_HDMI_cable.stl
83.5 x 10.3 x 96.2

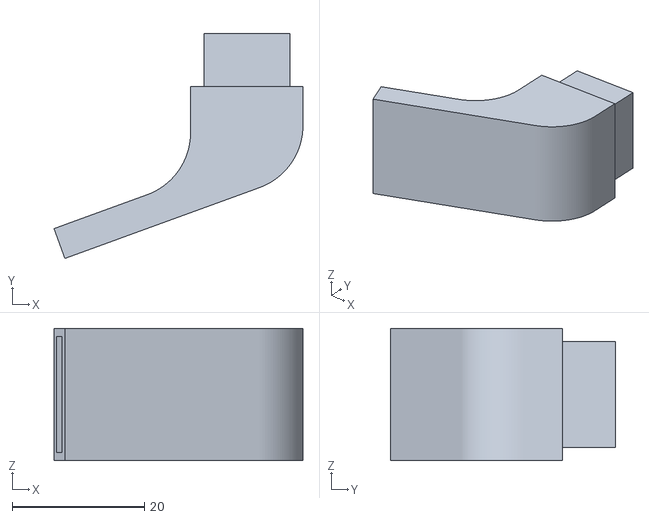
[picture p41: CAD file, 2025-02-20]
Consoles_and_Parts/Fan_Nozzle_V2.stl
37.6 x 34.0 x 20.0

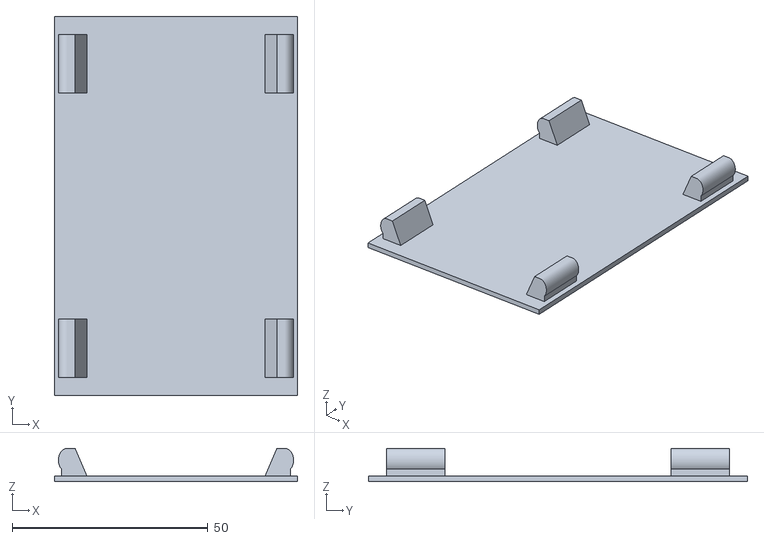
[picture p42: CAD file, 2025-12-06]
IdeaMaker_Models/Breaker_Filler_Plate_-_Schneider_-_4-UP.stl
62.0 x 96.8 x 8.50

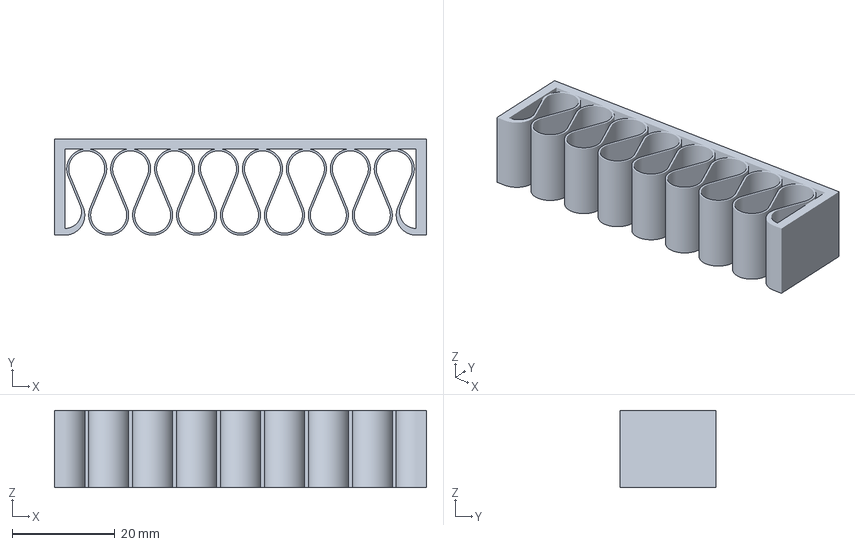
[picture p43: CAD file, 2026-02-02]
IdeaMaker_Models/Dani/Tape_8_3MF.3mf
72.4 x 18.8 x 15.0 mm

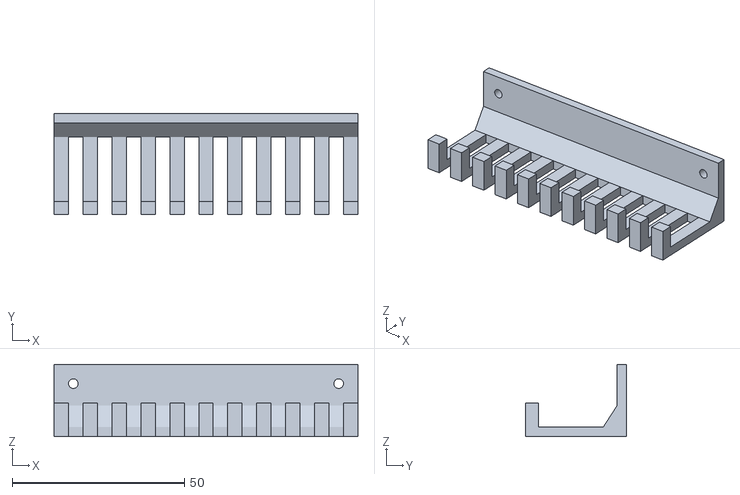
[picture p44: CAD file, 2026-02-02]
IdeaMaker_Models/Dani/cable_management_thingy_v5.stl
88.2 x 29.4 x 21.0

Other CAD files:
IdeaMaker_Models/Breaker_Filler_Plate_-_Schneider_-_3-UP.stl
Consoles_and_Parts/Rpi_4_Case_Top.stl
IdeaMaker_Models/Breaker_Filler_Plate_-_Thomas__Betts_-_1-UP.stl
Consoles_and_Parts/Rpi_4_Case_Bottom.stl
Consoles_and_Parts/Spacer_for_extruder_part.stl
Consoles_and_Parts/belt_tensioner_A2.stl
Consoles_and_Parts/belt_tensioner_B2.stl
IdeaMaker_Models/130%_Toshiba_Távirányító.010.stl
IdeaMaker_Models/20240427_double_values_square_calibration.stl
IdeaMaker_Models/25mm_cube.stl
IdeaMaker_Models/68mm_desk_cut.stl
IdeaMaker_Models/68mm_desk_grommet.stl
IdeaMaker_Models/68mm_desk_solid.stl
IdeaMaker_Models/Alfa_Romeo_keychain.stl
IdeaMaker_Models/Alfa_romeo_logo_spinner.stl
IdeaMaker_Models/AntennaMount_Sakura.stl
IdeaMaker_Models/Bevásárló_Coin_Cart_v2.STL
IdeaMaker_Models/Bird_and_Flovers.stl
IdeaMaker_Models/Bird_and_Flovers_10mm.stl
IdeaMaker_Models/BlackPantherForKGMS.stl
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

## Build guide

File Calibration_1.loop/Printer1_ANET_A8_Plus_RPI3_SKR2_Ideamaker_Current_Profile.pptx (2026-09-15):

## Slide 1

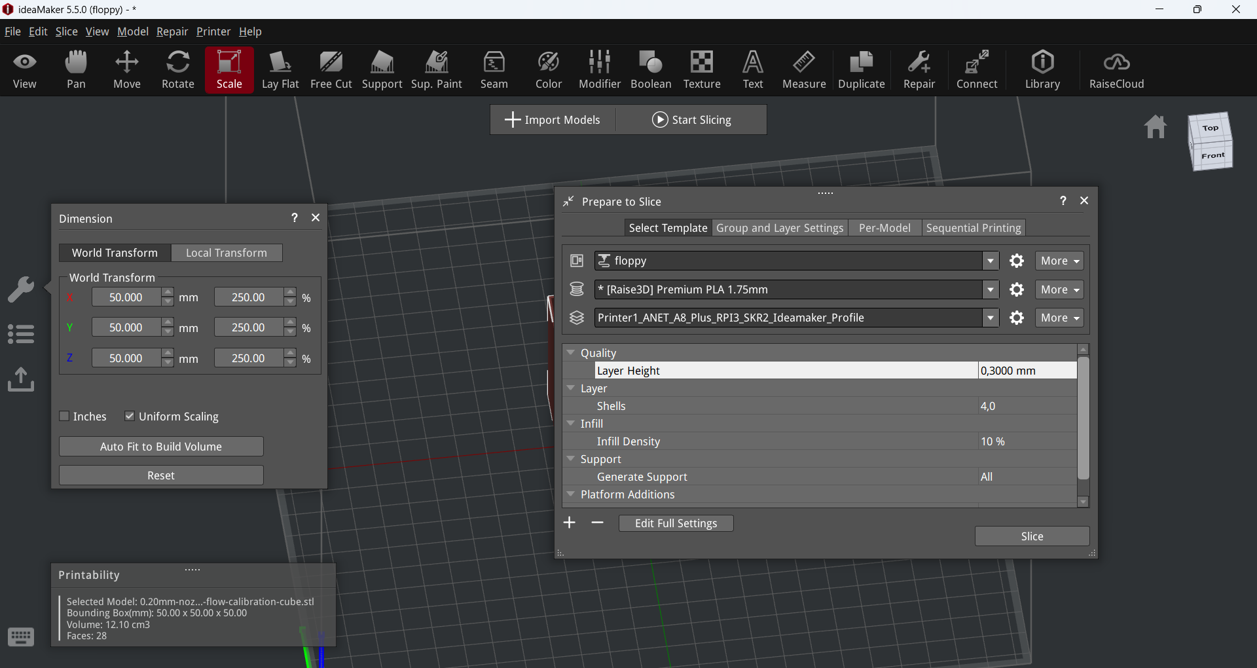
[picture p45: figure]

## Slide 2

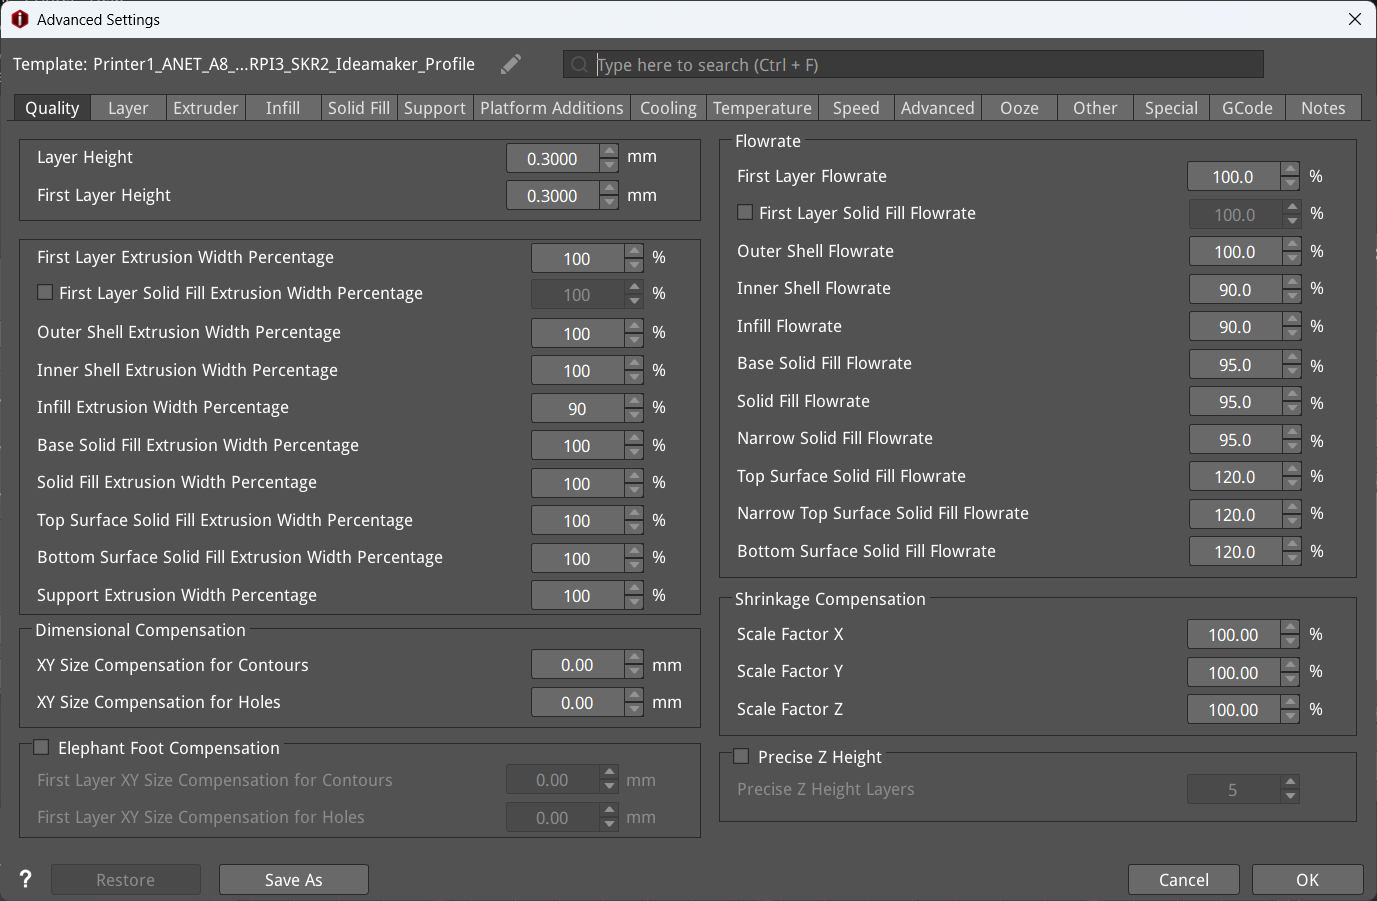
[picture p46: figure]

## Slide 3

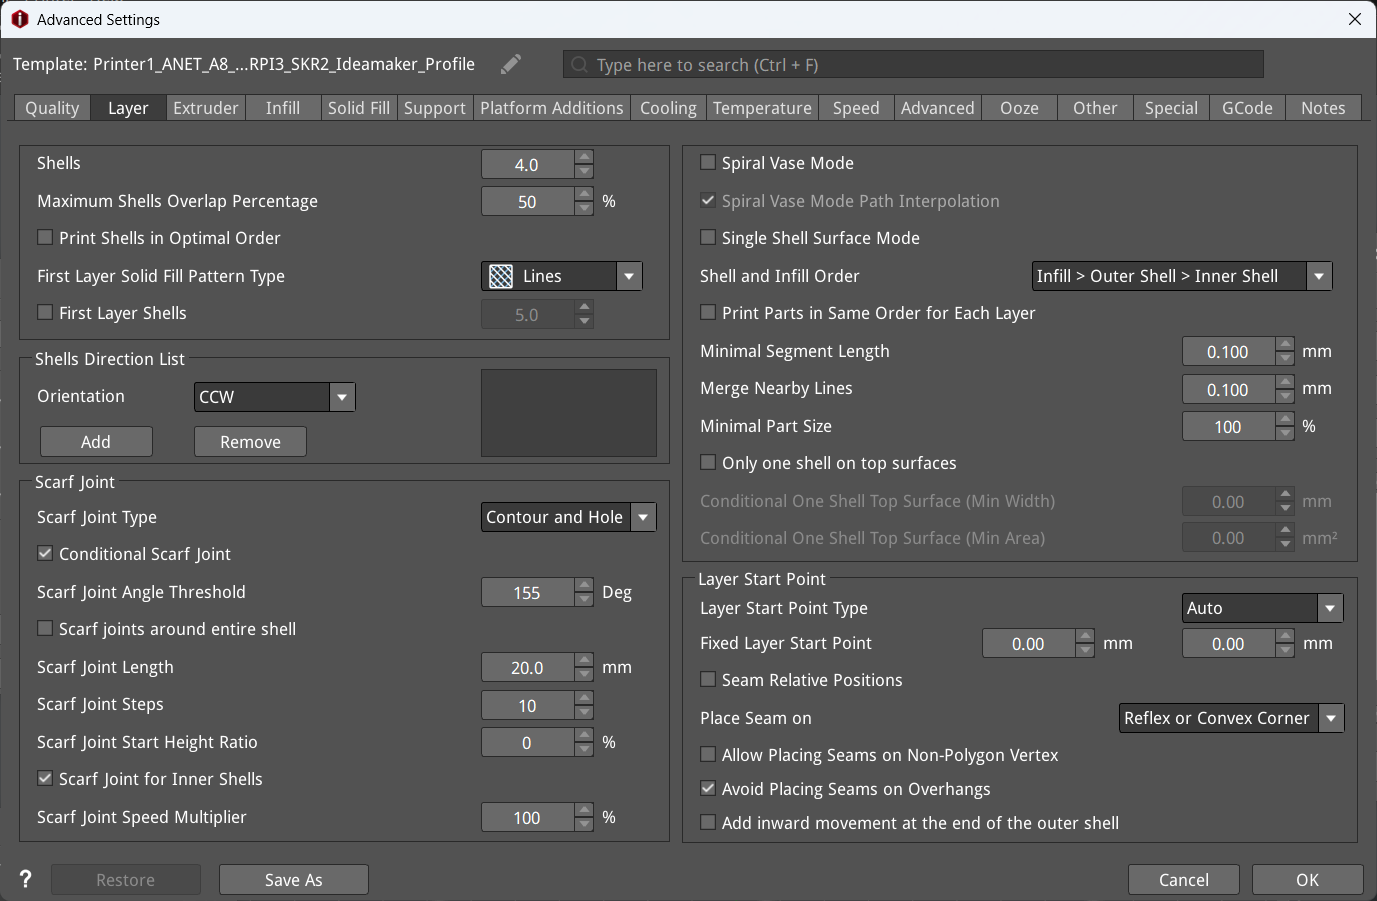
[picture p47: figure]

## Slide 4

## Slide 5

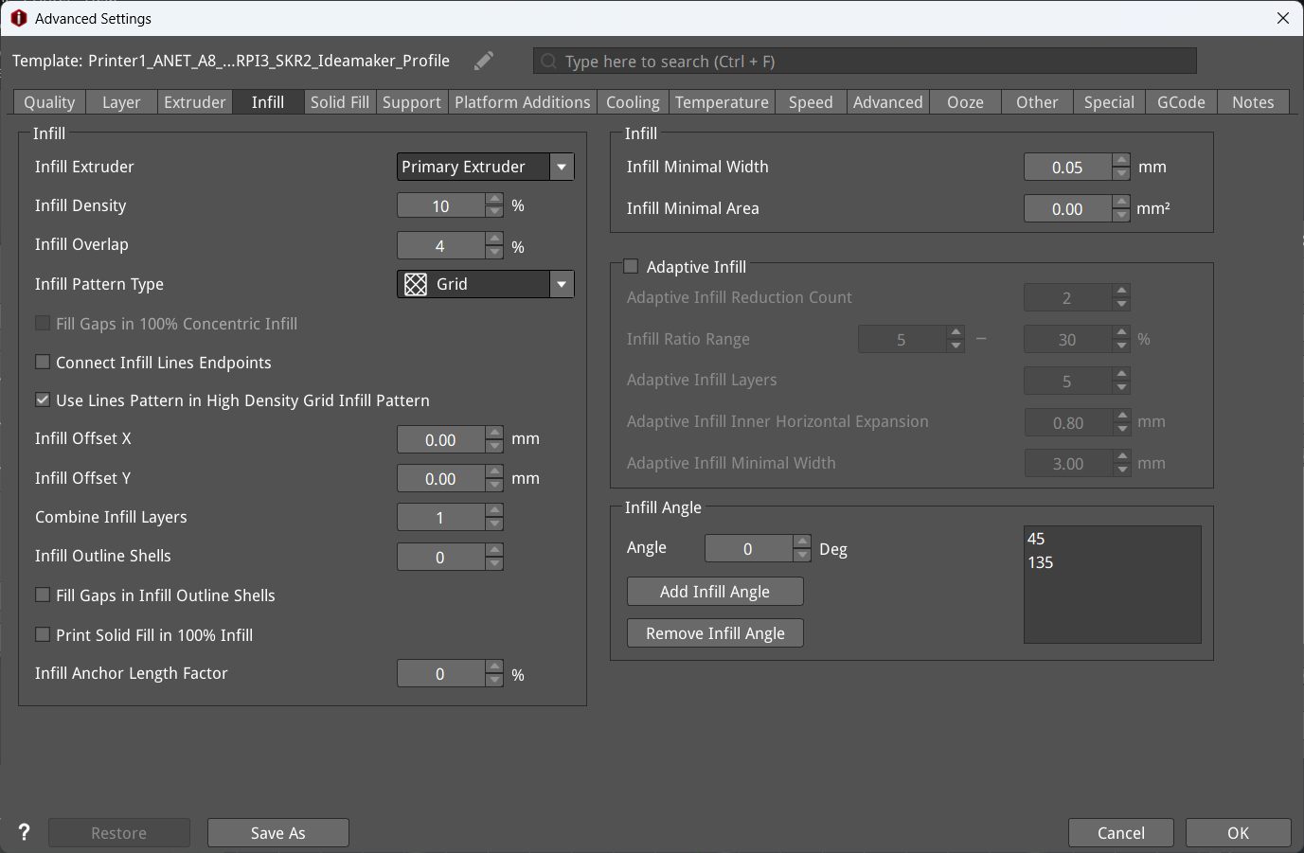
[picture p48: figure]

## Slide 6

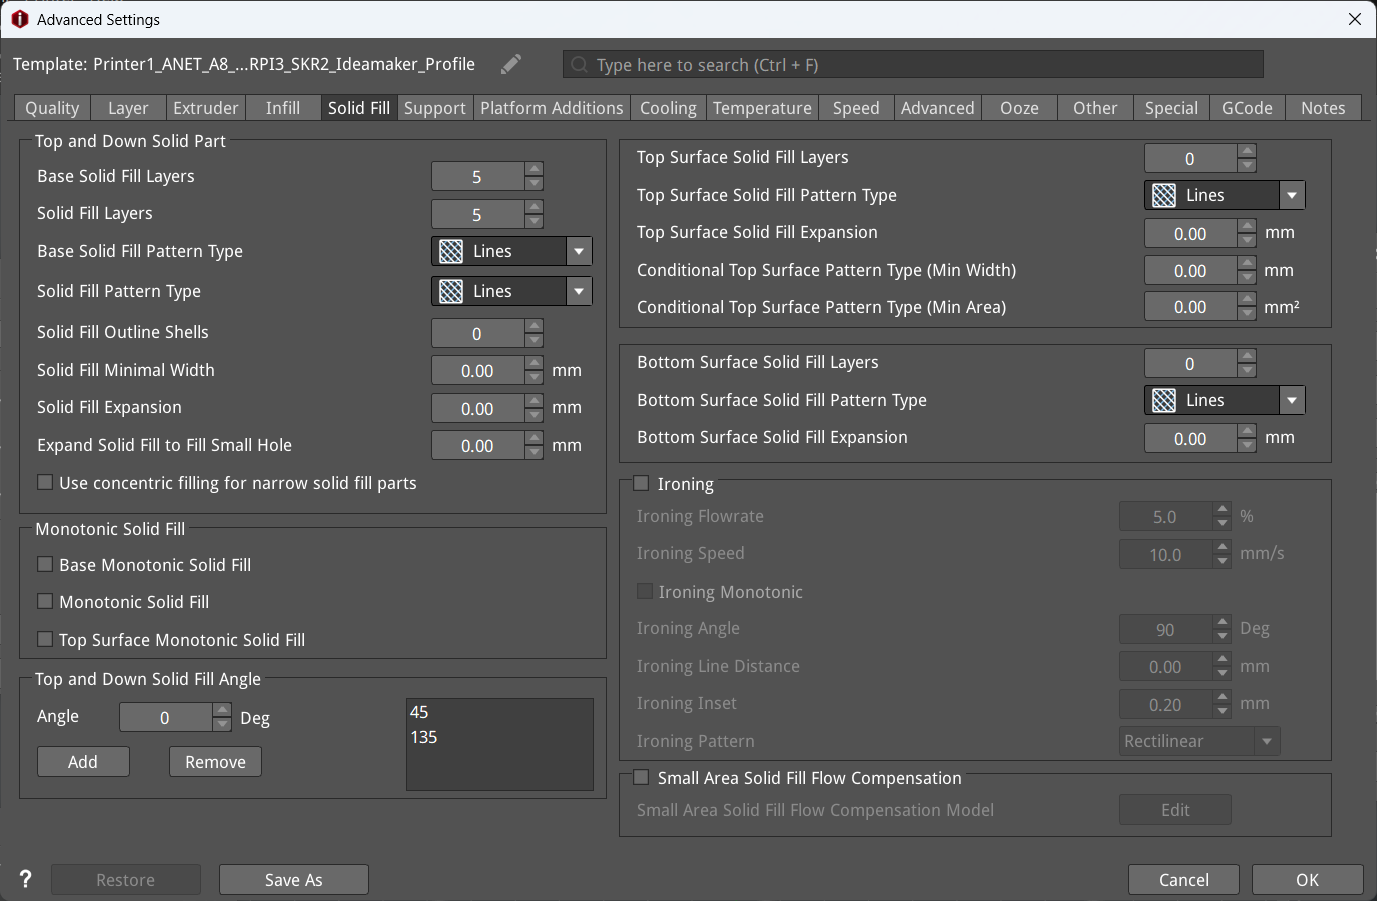
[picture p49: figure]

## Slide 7

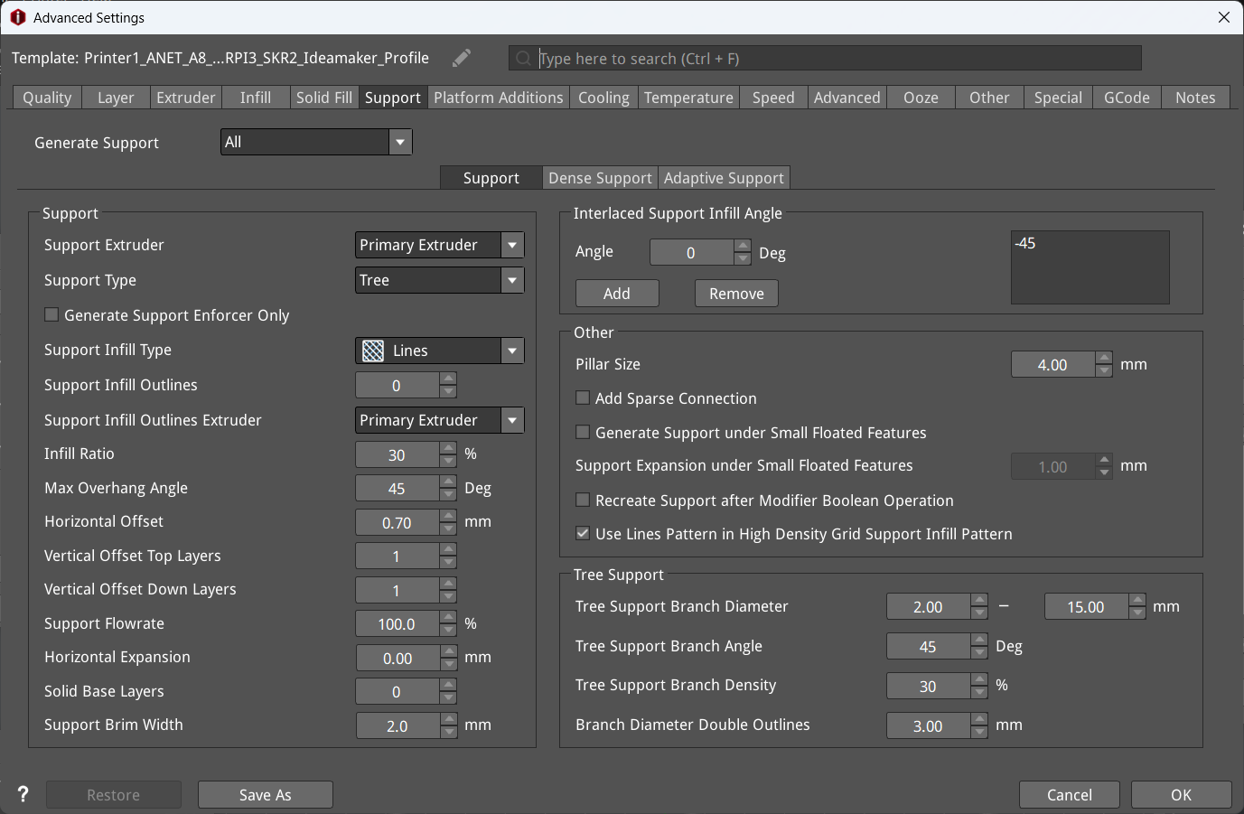
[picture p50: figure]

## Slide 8

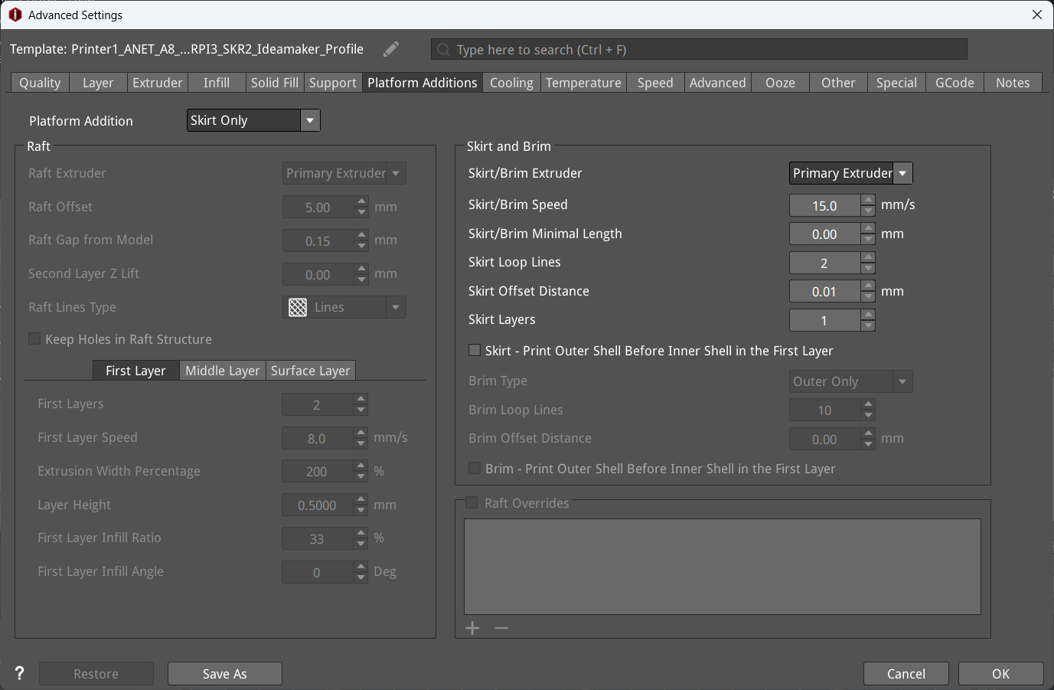
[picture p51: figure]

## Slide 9

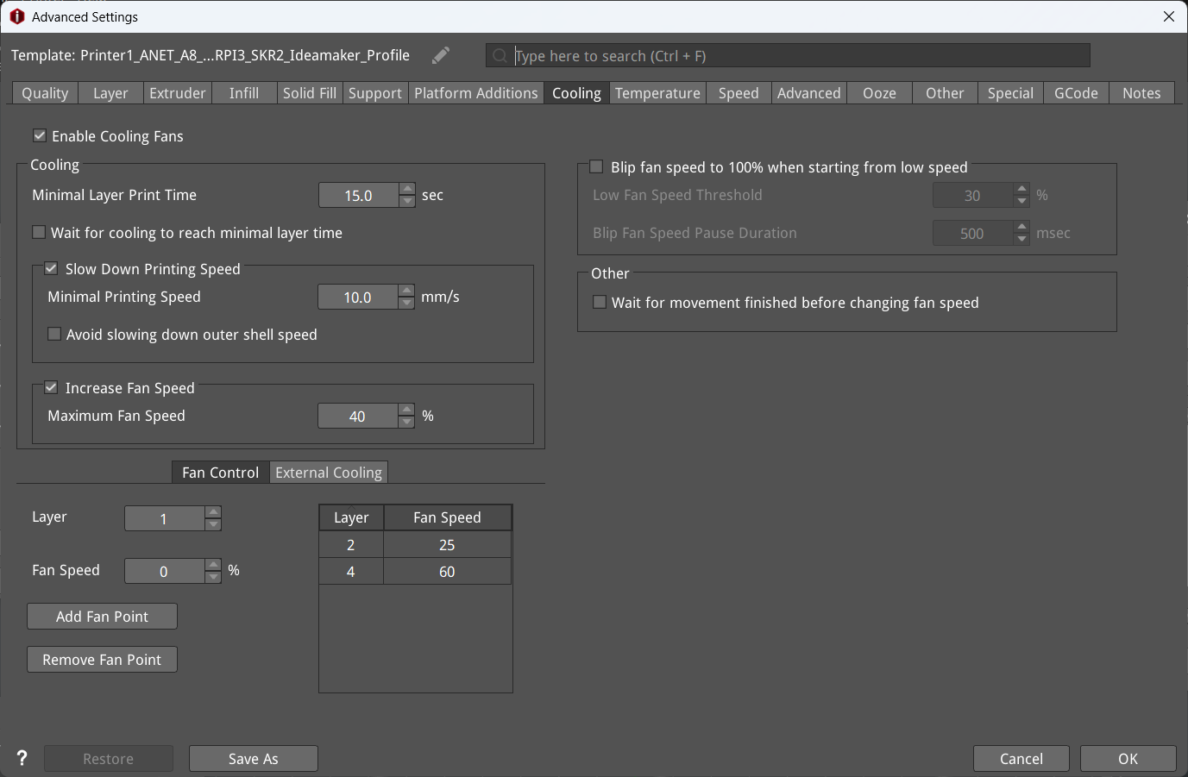
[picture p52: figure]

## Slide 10

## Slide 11

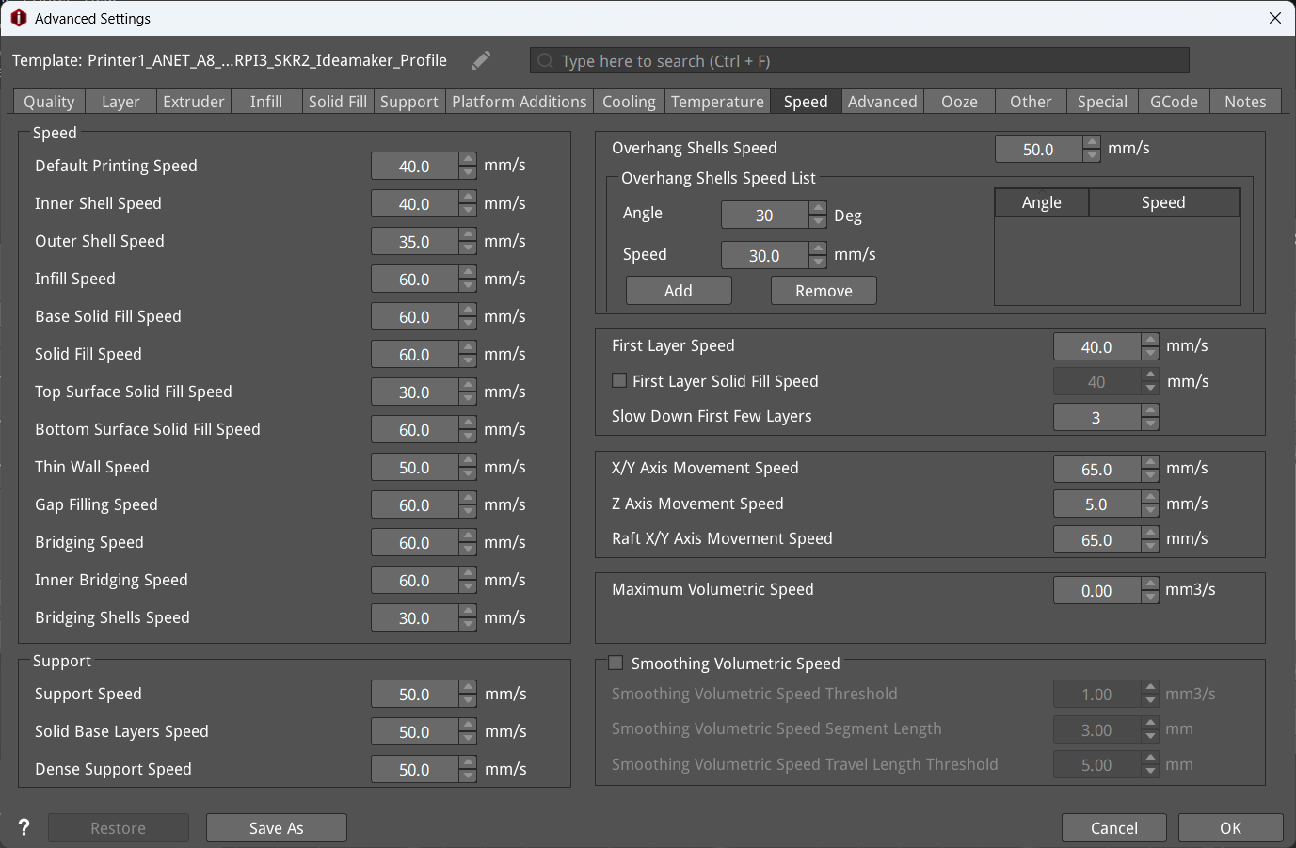
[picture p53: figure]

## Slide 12

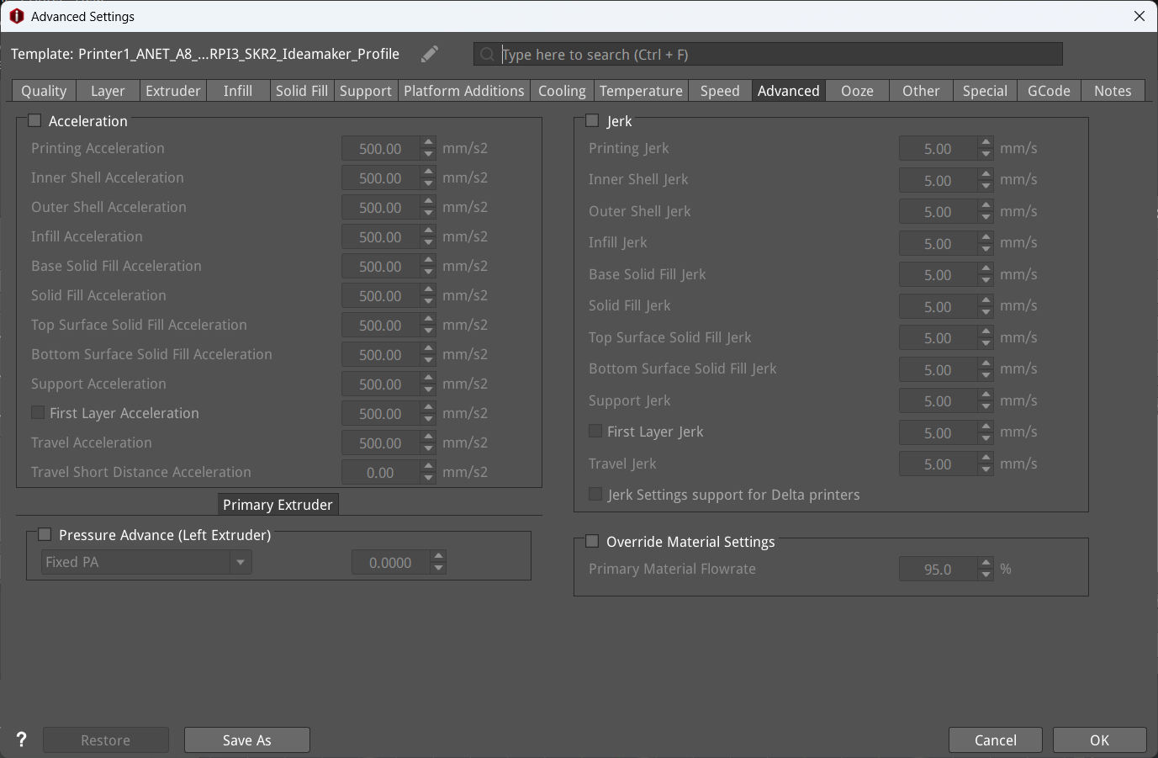
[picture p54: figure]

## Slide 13

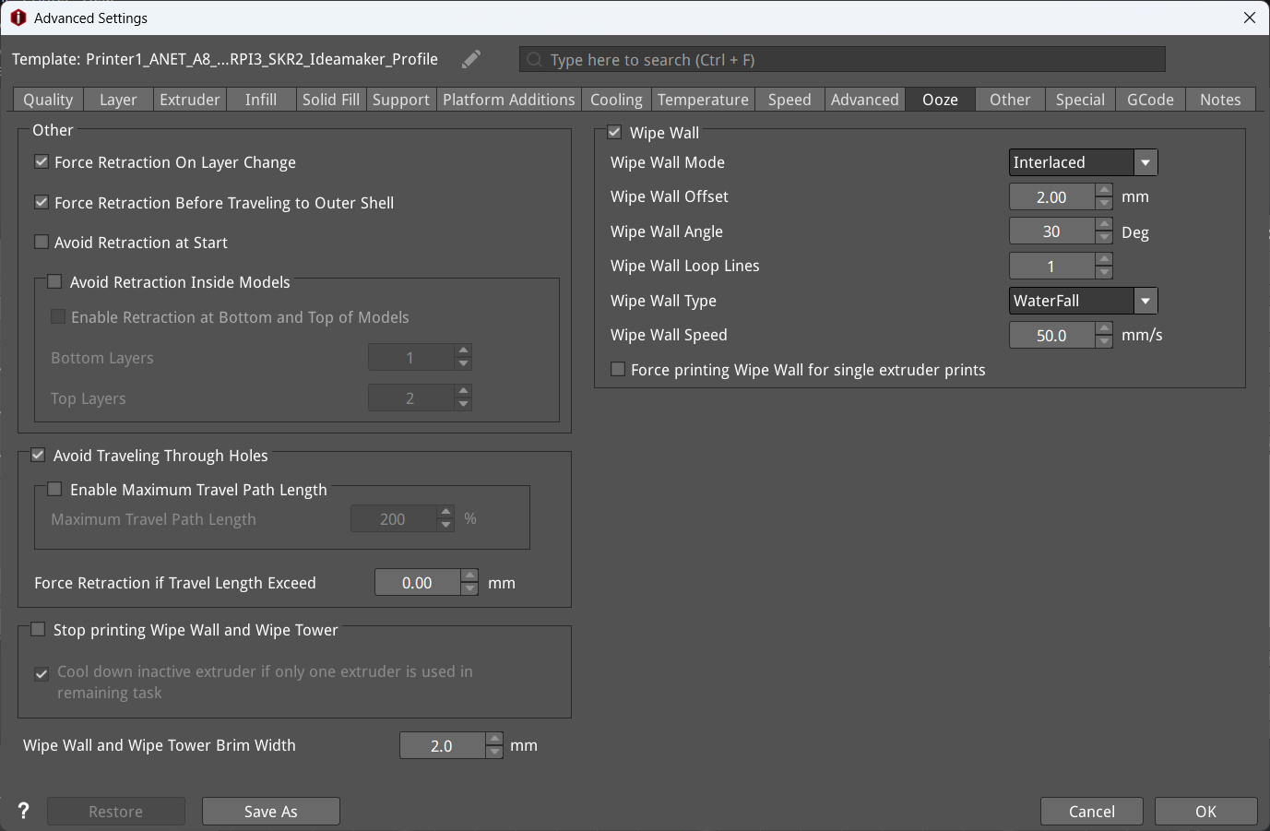
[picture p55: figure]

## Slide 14

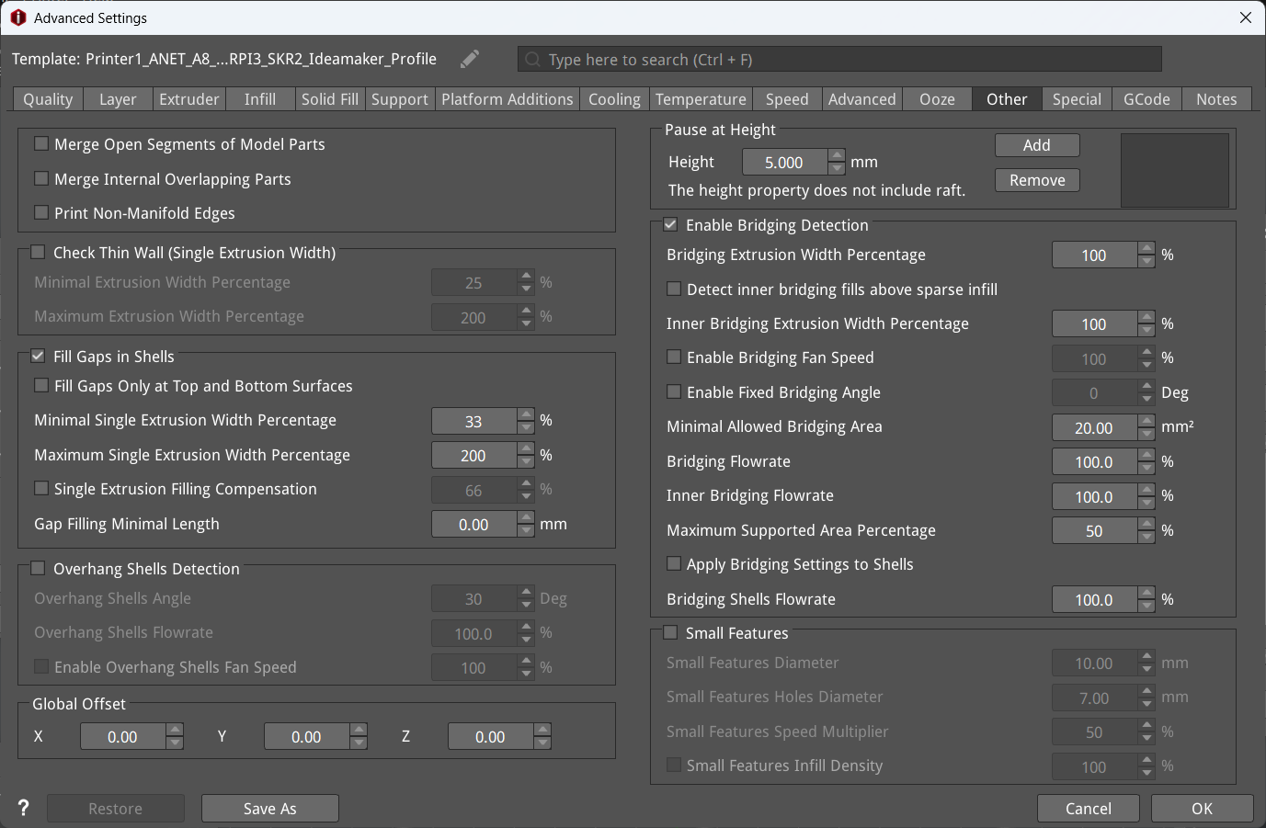
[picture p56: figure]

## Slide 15

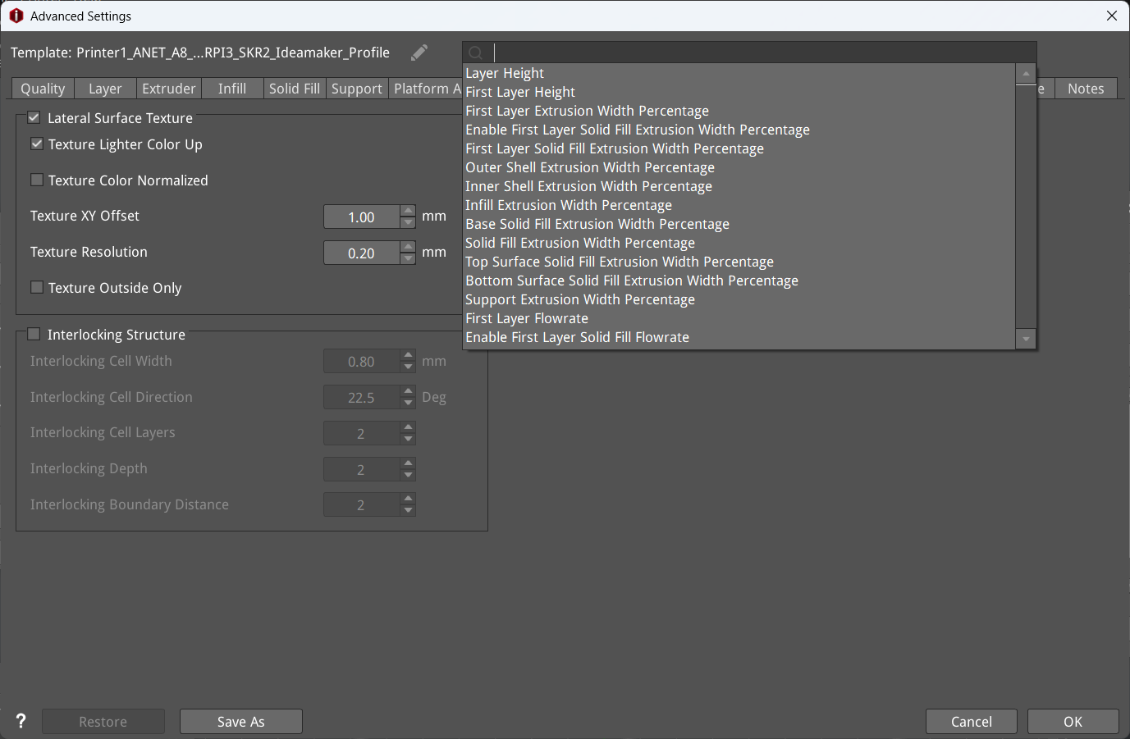
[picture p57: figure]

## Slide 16

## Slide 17

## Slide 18

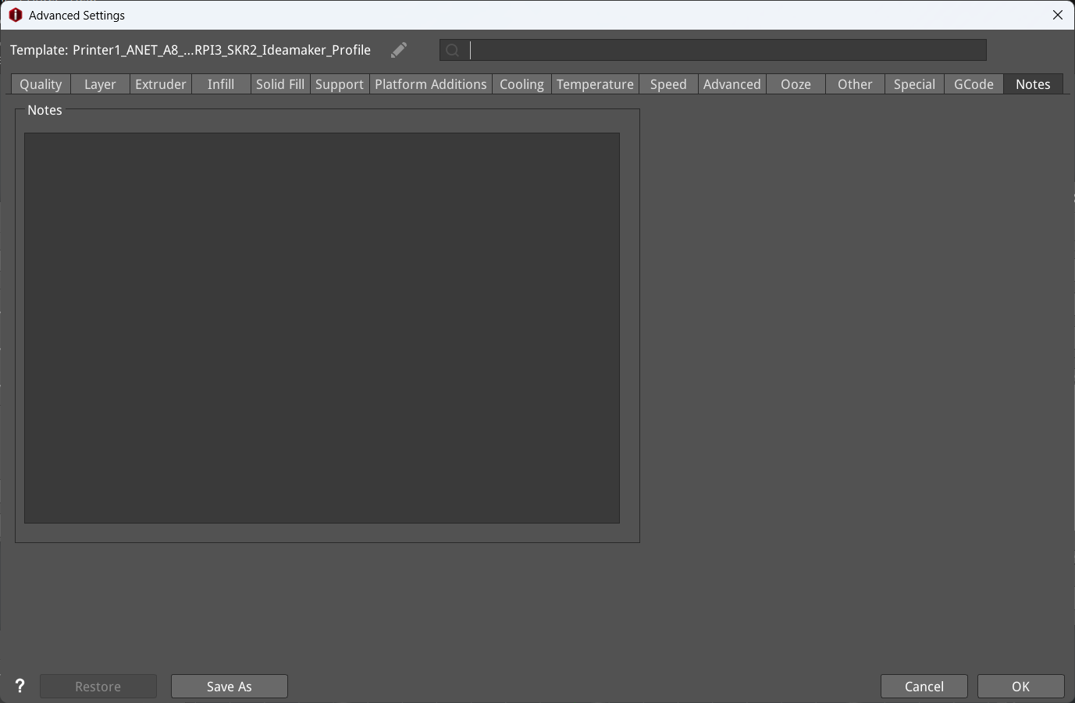
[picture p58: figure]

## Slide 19

Printer1_ANET_A8_Plus_RPI3_SKR2_Ideamaker_Current_Profile.bin

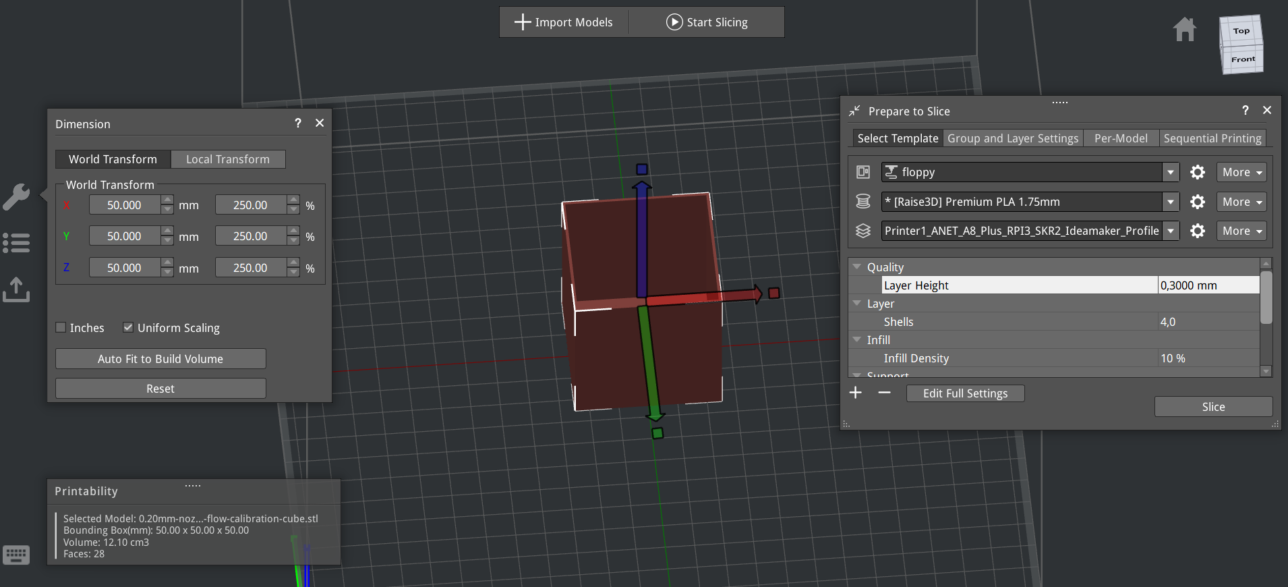
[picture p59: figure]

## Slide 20

Printer1_ANET_A8_Plus_RPI3_SKR2_Ideamaker_Current_Profile
X axle 48,63mm instead of 50mm

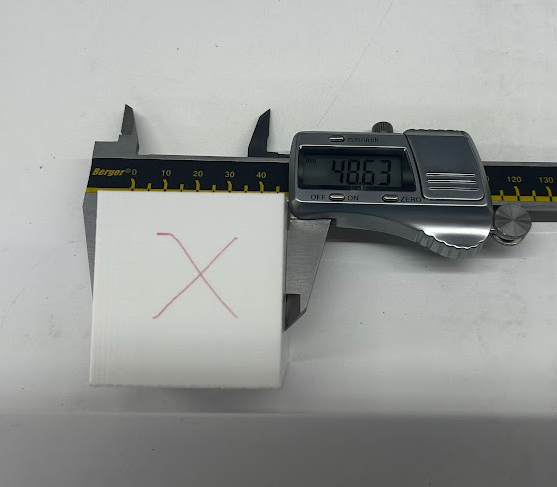
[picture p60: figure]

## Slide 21

Printer1_ANET_A8_Plus_RPI3_SKR2_Ideamaker_Current_Profile
Y axle 49,76mm instead of 50mm

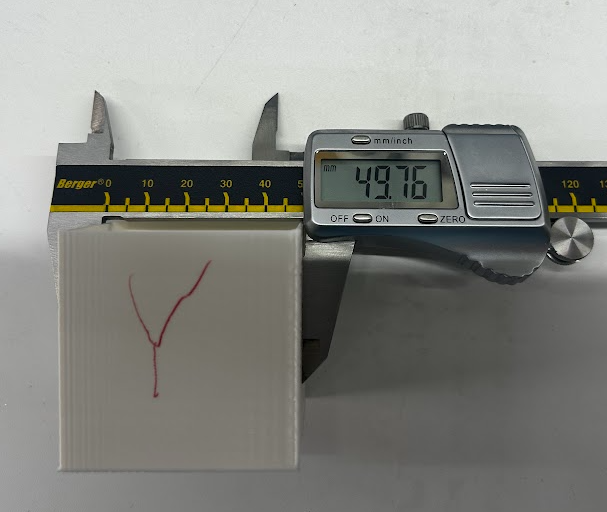
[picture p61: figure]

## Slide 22

Printer1_ANET_A8_Plus_RPI3_SKR2_Ideamaker_Current_Profile.bin
Z axle 50,21mm instead of 50mm

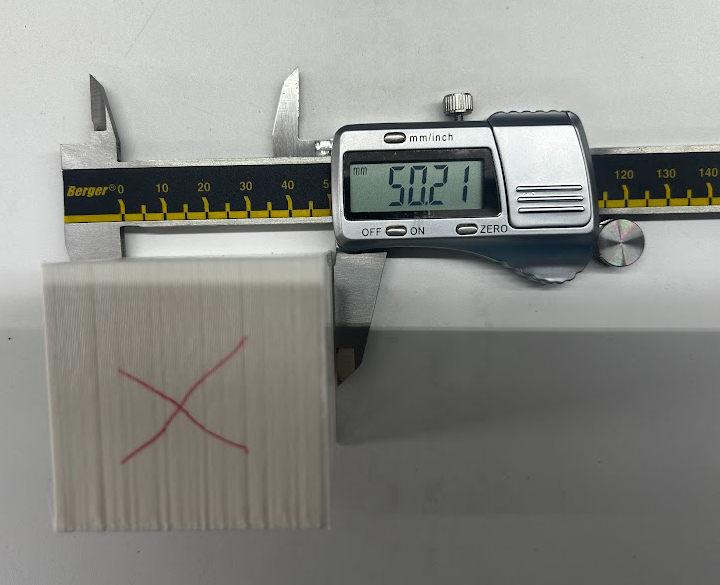
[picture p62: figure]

Z

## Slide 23

Printer1_ANET_A8_Plus_RPI3_SKR2_Ideamaker_Current_Profile.bin
Edge problem overflow

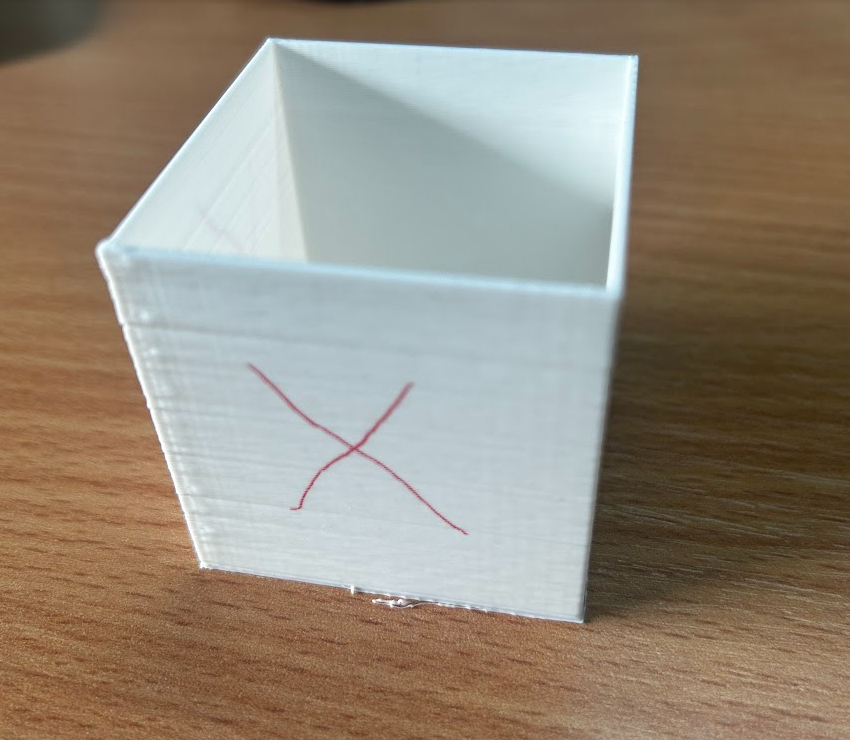
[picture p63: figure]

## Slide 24

Printer1_ANET_A8_Plus_RPI3_SKR2_Ideamaker_Current_Profile.bin
Edge problem. 0,3mm layer height, first layer height 0,3mm

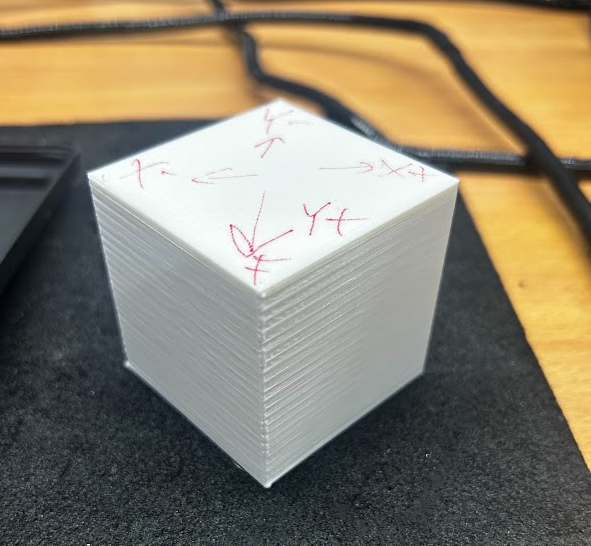
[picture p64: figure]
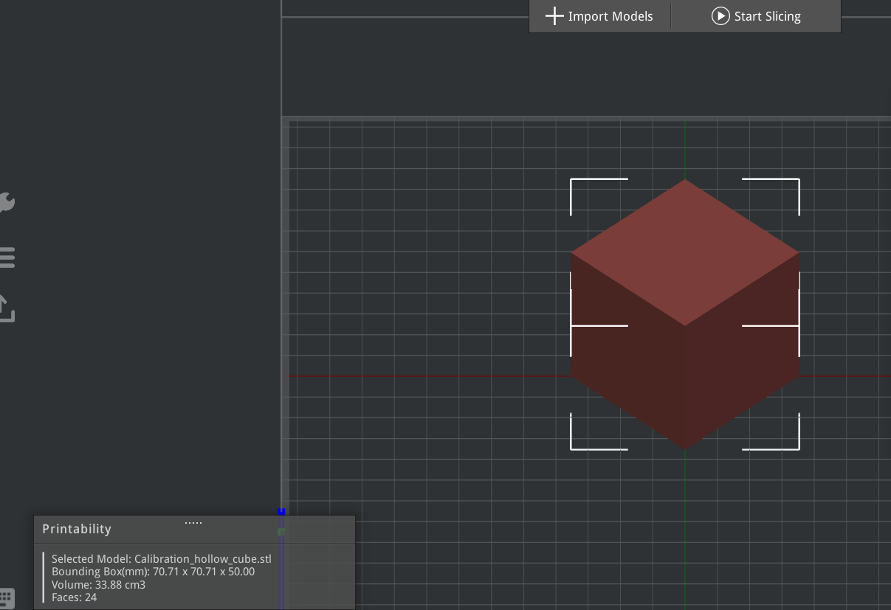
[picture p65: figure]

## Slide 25

Printer1_ANET_A8_Plus_RPI3_SKR2_Ideamaker_Current_Profile.bin
Edge problem. 0,3mm layer height, first layer height 0,3mm. Hotend PID calibration,extruder calibration

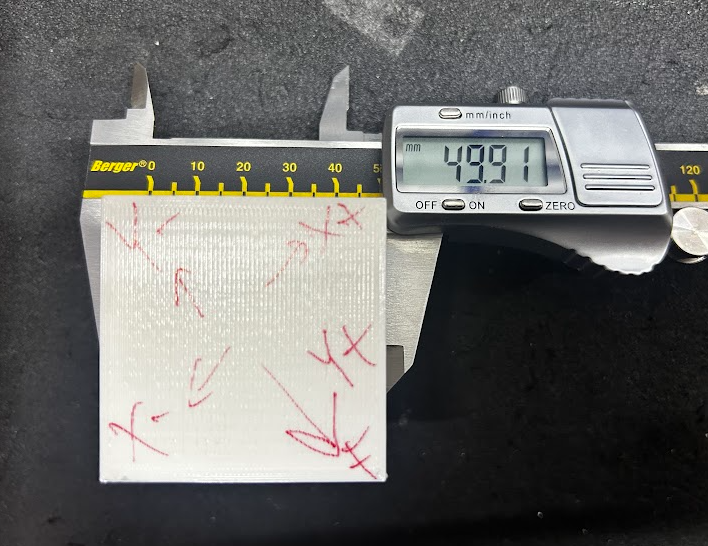
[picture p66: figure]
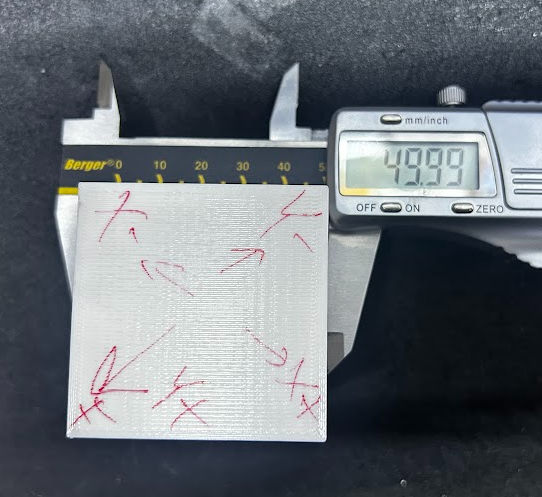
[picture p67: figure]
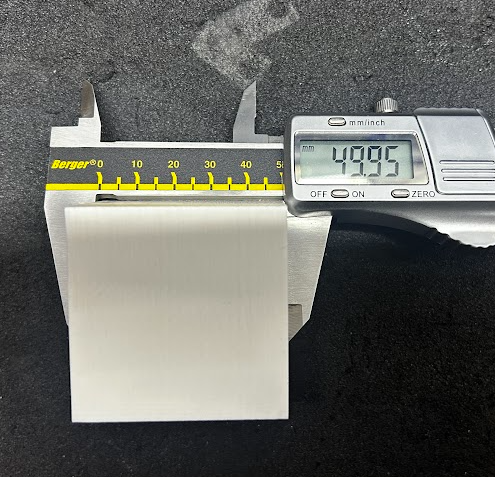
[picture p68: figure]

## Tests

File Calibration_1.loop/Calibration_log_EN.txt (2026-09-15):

===============================================================================
ANET A8 PLUS + RPI3 + SKR2 + KLIPPER/MAINSAIL + IDEAMAKER
CALIBRATION LOG
Date: 2026-09-13
===============================================================================

-------------------------------------------------------------------------------
0. STARTING POINT
-------------------------------------------------------------------------------
Printer:    Anet A8 Plus, converted to SKR2 + Raspberry Pi 3B+
Firmware:   Klipper
Interface:  Mainsail
Slicer:     IdeaMaker
Probe:      BLTouch / 3D Touch (x_offset: -30, y_offset: -25)

Test object: 50 x 50 x 50 mm calibration cube
Source document:
  Calibration/Printer1_ANET_A8_Plus_RPI3_SKR2_Ideamaker_Current_Profile.pdf
  (23 pages, IdeaMaker profile screenshots + photos of the printed cube)

PROBLEMS:
  1) Dimensional inaccuracy on all three axes
  2) "Edge problem" - bulging / oozing at the corners when the head turns
     from the X direction into the Y direction

-------------------------------------------------------------------------------
1. MEASUREMENT RESULTS IN CHRONOLOGICAL ORDER
-------------------------------------------------------------------------------

+---------+-----------+-----------+-----------+------------------------------+
| Test    | X (mm)    | Y (mm)    | Z (mm)    | Settings                     |
+---------+-----------+-----------+-----------+------------------------------+
| #1      | 48.63     | 49.76     | 50.21     | X rot.dist = 40.9            |
|         | (-1.37)   | (-0.24)   | (+0.21)   | Y rot.dist = 40              |
|         |           |           |           | z_offset = 1.15              |
|         |           |           |           | no pressure_advance          |
|         |           |           |           | max_accel = 3000             |
+---------+-----------+-----------+-----------+------------------------------+
| #2      | 49.74     | 49.79     | 50.17     | X rot.dist = 40  (fixed)     |
|         | (-0.26)   | (-0.21)   | (+0.17)   | Y rot.dist = 40              |
|         |           |           |           | z_offset = 1.15              |
|         |           |           |           | pressure_advance = 0.05      |
|         |           |           |           | max_accel = 1500             |
+---------+-----------+-----------+-----------+------------------------------+
| #3      | 49.94     | 49.97     | 50.06     | X rot.dist = 40              |
|         | (-0.06)   | (-0.03)   | (+0.06)   | Y rot.dist = 40              |
|         |           |           |           | z_offset = 1.25 (+0.10)      |
|         |           |           |           | pressure_advance = 0.05      |
|         |           |           |           | max_accel = 1500             |
+---------+-----------+-----------+-----------+------------------------------+

EVALUATION OF TEST #3
---------------------
All three axes are within 0.1 mm. This is already a VERY GOOD result:
  X: -0.12 %
  Y: -0.06 %
  Z: +0.12 %
For comparison, the X error in test #1 was -2.74 %.

Z: the prediction was 50.07, the actual value is 50.06 -> the model works
   exactly as expected.

X/Y: UNEXPECTED IMPROVEMENT. Compared to #2, X grew by +0.20 mm and
Y by +0.18 mm, even though only the z_offset changed in printer.cfg.
TWO POSSIBLE EXPLANATIONS:
  a) XY Size Compensation was set in IdeaMaker in the meantime
     (+0.12 mm -> that is +0.24 mm across two sides, which matches the
      measured +0.18...+0.20 mm improvement well)  <- THIS IS LIKELY
  b) The larger squish changed the widening of the first layer
     (elephant foot), and the measurement captured that

TO BE CLARIFIED: check the XY Size Compensation value in the IdeaMaker
profile and record it here. Without it we do not know what must not be
changed.

-------------------------------------------------------------------------------
2. DIAGNOSIS - X AXIS ERROR (SOLVED)
-------------------------------------------------------------------------------

First assumption (it was WRONG):
  The -2.74 % X error is mechanical (loose belt, slipping pulley).

Correction, after it turned out that X rot.dist was 40.9 during the test:

  Formula:  measured = 50 x RD_actual / RD_configured

  X:  48.63 = 50 x RD / 40.9  ->  RD_actual = 39.78
  Y:  49.76 = 50 x RD / 40.0  ->  RD_actual = 39.81

  The two axes are practically identical -> THERE IS NO mechanical fault.
  The whole deviation was caused by the incorrectly entered 40.9.

SOLUTION: X rotation_distance = 40 (theoretical value for a 16-tooth GT2
          pulley)
STATUS:   DONE - confirmed by test #2 (prediction 49.73 / actual 49.74)

-------------------------------------------------------------------------------
3. DIAGNOSIS - REMAINING X/Y ERROR (IN PROGRESS)
-------------------------------------------------------------------------------

After test #2:
  X error: -0.26 mm (-0.52 %)
  Y error: -0.21 mm (-0.42 %)
  Average: -0.235 mm

The two axes are within 0.05 mm of each other -> symmetric error.
The rotation_distance MUST NOT BE TOUCHED ANY MORE, this is not a
stepper error.

Possible causes:
  a) Slicer outer wall extrusion width -> FIXED offset error
  b) PLA thermal shrinkage (~0.3-0.5 %) -> PROPORTIONAL (scale) error

SOLUTION for case "a":
  IdeaMaker -> Quality -> XY Size Compensation for Contours: +0.12 mm
  (half of the error, because it appears on two sides: 0.235 / 2)
  Expected result: X ~49.98 / Y ~50.03

SOLUTION for case "b":
  Scale the model to 100.45 %

HOW TO TELL THEM APART:
  Print a 100 x 20 x 1 mm bar.
    - If the shortfall is ~0.24 mm -> FIXED offset -> keep the +0.12 mm
      compensation
    - If the shortfall is ~0.46 mm -> SHRINKAGE -> scaling is needed instead

STATUS: NOT DONE YET

-------------------------------------------------------------------------------
4. DIAGNOSIS - Z AXIS (IN PROGRESS)
-------------------------------------------------------------------------------

IMPORTANT PRINCIPLE:
  The Z error does NOT come from stepper_z rotation_distance!
  Because of the TR8x8 lead screw, rotation_distance = 8 is mathematically
  exact, and it must NEVER be modified.

  From the second layer on, every layer is accurate. ALL height error is
  created in the FIRST LAYER: if the nozzle is too high, the first layer
  is thicker than nominal, and this is added as a constant error to the
  whole model.

  -> The solution is always the [bltouch] z_offset.

SIGN RULE IN KLIPPER:
  LARGER z_offset = the nozzle is CLOSER to the bed = MORE squish
                  = the printed part will be SHORTER

CALCULATION:
  Test #1: 50.21 mm with z_offset 1.15 -> +0.21 correction would be needed
  Test #2: 50.17 mm with z_offset 1.15 -> +0.17 correction would be needed
  Ideal value is therefore: 1.15 + 0.17 = 1.32

APPLIED STEP:
  z_offset 1.15 -> 1.25 (only +0.10, a cautious approach to protect the bed)
  Expected #3 result: Z ~50.07 mm
  ACTUAL #3 result: 50.06 mm -> the prediction was correct

POSSIBLE FURTHER FINE-TUNING (optional):
  For the remaining +0.06 mm, z_offset 1.25 -> 1.31 would be needed.
  BUT: 0.06 mm is already within the error margin of the caliper and the
  surface roughness, and more squish can cause elephant foot.
  RECOMMENDATION: LEAVE IT AT 1.25.

STATUS: DONE (within acceptable error margin)

-------------------------------------------------------------------------------
5. Z-OFFSET CALIBRATION - STEP BY STEP (REFERENCE)
-------------------------------------------------------------------------------

PREPARATION
  - Bed heated to operating temperature (e.g. 60 C for PLA)
  - Nozzle at ~150 C (important because of thermal expansion!)
  - Nozzle must be clean
  - Sheet of paper ready (~0.1 mm)

STEPS (Mainsail console)
  1.  G28
  2.  PROBE_CALIBRATE
      -> the BLTouch probes, the head moves aside and lowers
      -> the "Z Offset Calibration" panel appears with + / - buttons
  3.  TESTZ Z=-0.17          (or on the panel: -0.05 x3 and -0.02 x1)
  4.  Paper test:
        Good:       it slides, but you can feel it scratching
        Too loose:  TESTZ Z=-0.02
        Too tight:  TESTZ Z=+0.02
  5.  ACCEPT
      -> the console prints: "bltouch: z_offset: 1.320"
  6.  SAVE_CONFIG
      NOTE: this RESTARTS Klipper, that is normal!
  7.  Verification: the SAVE_CONFIG block should contain
        #*# [bltouch]
        #*# z_offset = 1.320
  8.  Redo the bed mesh (the Z reference has changed):
        G28
        BED_MESH_CALIBRATE
        SAVE_CONFIG
  9.  Reprint the test cube

BAILING OUT: the ABORT command at any time, without saving

WARNING:
  Once SAVE_CONFIG has run, the z_offset value at the TOP of the file becomes
  ineffective - the SAVE_CONFIG block always overrides it. Do not be surprised
  that the old number stays there.

  If you want to edit the top of the file MANUALLY: first DELETE the
  "#*# [bltouch]" and "#*# z_offset = ..." lines from the SAVE_CONFIG block,
  then run FIRMWARE_RESTART.

-------------------------------------------------------------------------------
6. SYMPTOM: MAINSAIL DISPLAYED -4.85
-------------------------------------------------------------------------------

CASE: While adjusting the Z offset, Mainsail showed a value of -4.85.
      The user (correctly) did not start the movement.

EXPLANATION:
  What was shown is NOT the offset, but the CURRENT Z POSITION OF THE HEAD.
  This appears when you look at the dashboard "Z offset" live adjust field
  instead of the dedicated PROBE_CALIBRATE panel.
  The two are SEPARATE things.

RULE: if you see a Z below -4 before a movement, always stop.

-------------------------------------------------------------------------------
7. CORNER OOZING ("EDGE PROBLEM") - IN PROGRESS
-------------------------------------------------------------------------------

CAUSE:
  - Pressure Advance was not configured either in IdeaMaker or in Klipper
  - Acceleration and Jerk are disabled in the slicer (this is good, Klipper
    handles them), but Klipper's 3000 mm/s^2 acceleration is too much for
    the acrylic frame

APPLIED SETTINGS (printer.cfg):
  [extruder]
    pressure_advance: 0.05
    pressure_advance_smooth_time: 0.040
  [printer]
    max_accel: 1500              (instead of 3000)
    square_corner_velocity: 5.0

NEXT STEP - PA CALIBRATION based on the evaluation of print #3:
  - If improved but still faulty  -> go towards 0.07 ... 0.10
  - If nothing changed            -> probably a BOWDEN setup -> 0.4 ... 0.8
  - If the corners now pull in (under-extrusion in turns) -> back to 0.03
  - If the corners still ooze after PA -> square_corner_velocity 5.0 -> 3.0

Official guide: https://www.klipper3d.org/Pressure_Advance.html

STATUS: AWAITING EVALUATION

-------------------------------------------------------------------------------
8. PRINTER.CFG - CHANGES ALREADY MADE
-------------------------------------------------------------------------------

(VERIFIED AGAINST THE RUNNING printer.cfg: 2026-09-13)

[stepper_x]
  rotation_distance:  40.9  ->  40          (fix for the X dimension error)

[extruder]
  rotation_distance: 33.500 -> 35.845       (E-step calibration, see sect. 11)
  control/pid_K*: COMMENTED OUT in the top section, the values live in the
                  SAVE_CONFIG block (39.518 / 3.421 / 114.109)
  min_temp:            0    ->  10          (at 0 Klipper does not detect a
                                             detached thermistor)
  max_extrude_only_distance:  -  ->  150    (without it "G1 E100" errors out
                                             during extruder calibration,
                                             the default is only 50 mm)
  pressure_advance:           -  ->  0.05   (against corner oozing)
  pressure_advance_smooth_time: - -> 0.040

[heater_bed]
  min_temp:            0    ->  10          (thermistor protection)

[printer]
  max_accel:        3000    ->  1500        (acrylic frame + ringing)
  square_corner_velocity:  - ->  5.0        (stated explicitly, this is the
                                             default value)

[bltouch]
  z_offset:         1.15    ->  1.25        (fix for the Z dimension error,
                                             a cautious step; the calculated
                                             ideal is 1.32)
  The "#*# [bltouch]" section in the SAVE_CONFIG block is EMPTY (it holds no
  z_offset line), therefore the 1.25 at the top of the file is the EFFECTIVE
  value.

-------------------------------------------------------------------------------
9. PRINTER.CFG - STILL OPEN ITEMS
-------------------------------------------------------------------------------

(A) HOTEND PID CALIBRATION  -- DONE, 2026-09-13
    Original (Klipper stock example value, never calibrated):
      pid_Kp = 22.2    pid_Ki = 1.08    pid_Kd = 114

    PID_CALIBRATE HEATER=extruder TARGET=<printing temperature>
    SAVE_CONFIG

    Measured values:
      pid_Kp = 39.518  pid_Ki = 3.421   pid_Kd = 114.109

    DEVIATION:
      Kp: +78 %
      Ki: +217 %   <-- THIS IS THE KEY ONE
      Kd: ~0 %

    EVALUATION:
    Ki was set more than three times lower than required. The integral term
    is responsible for eliminating steady-state error; if it is too small,
    the heater follows the target sluggishly and with overshoots -> slow
    temperature oscillation -> fluctuating viscosity -> WAVY, UNEVEN WALL.
    This explains the moire-like pattern seen on the right-hand face in the
    "test #3" photo.

    IN THE RUNNING CFG: the values are in the [extruder] section of the
    SAVE_CONFIG block, and the control/pid_K* lines at the top of the file
    are commented out. This is the CORRECT state - do not uncomment them,
    because the SAVE_CONFIG block would override them anyway.

    STATUS: DONE

(B) [heater_fan fan2] (PB5)
    No "heater:" is specified, so by default it is tied to the extruder.
    If this is actually a mainboard cooling fan, it should be a
    [temperature_fan] instead, otherwise it only spins when the hotend is hot.

(C) LEFTOVER IN THE SAVE_CONFIG BLOCK
      #*# [stepper_z]
      #*# position_endstop = 0.300
    Leftover from when there was still a physical Z endstop. Since
    "probe:z_virtual_endstop" is used now, Klipper ignores it.
    It causes no error, but it can be deleted after the next SAVE_CONFIG.

(D) NO INPUT SHAPER
    It would be worth configuring against ringing / ghosting, based on an
    accelerometer or a ringing test tower.

-------------------------------------------------------------------------------
10. IDEAMAKER - SUGGESTED CHANGES
-------------------------------------------------------------------------------

DIMENSIONAL ACCURACY:
  Quality -> XY Size Compensation for Contours:  0  ->  +0.12 mm
             (finalize it only after the 100 mm test! see section 3)

CORNER OOZING:
  Extruder -> Coasting Distance:        0  ->  0.2 mm
  Quality  -> Outer Shell Flowrate:   100  ->  95 %
  Speed    -> Outer Shell:             35  ->  25 mm/s (until PA is done)

GENERAL QUALITY:
  Layer Height: 0.3 mm -> 0.2 mm
    (0.3 mm is the upper limit for a 0.4 mm nozzle; switching to 0.2 improves
     Z accuracy and the corners a lot)

LEAVE UNCHANGED:
  Advanced -> Acceleration and Jerk must stay DISABLED
              (it is correct that Klipper handles them)

-------------------------------------------------------------------------------
11. EXTRUDER CALIBRATION (E-STEP) -- DONE 2026-09-13
-------------------------------------------------------------------------------

This is the "real root cause" behind the flow / dimension / corner issues.

MEASUREMENT:
  Mark:              120 mm at the extruder inlet
  Command:           G1 E100 F60
  Remaining mark:    13 mm
  Actually fed:      120 - 13 = 107 mm

CALCULATION:
  RD_new = 33.500 x (107 / 100) = 35.845

RESULT:
  rotation_distance:  33.500  ->  35.845
  The extruder was pushing 7 % MORE material than required on ALL prints
  so far.

CONSEQUENCES:
  - This directly explains the CORNER OOZING: material already piles up in
    a turn, and on top of that there was a 7 % surplus.
  - It also contributed to the wavy wall (together with the bad PID).
  - THE CUBE DIMENSIONS WILL CHANGE! Because of the reduced material the
    walls become thinner -> the outer dimension may shrink slightly.
    -> The dimensional calibration (XY Size Compensation) MUST BE
       RE-EVALUATED.

IMPORTANT: if a Flowrate < 100 % or an XY Size Compensation is set in
IdeaMaker, it is now worth RESETTING them to default, because they were
compensating for the 7 % over-extrusion. Otherwise there will now be
under-extrusion.

STEPS TO REPEAT THE PROCEDURE:
  1. Heat the hotend to printing temperature
  2. Mark 120 mm on the filament at the extruder inlet
  3. G1 E100 F60        (slowly! that is why max_extrude_only_distance was
                         needed)
  4. Measure how much of the mark is left
  5. new_value = old_value x (actual / 100)
  6. Write it into printer.cfg, then run FIRMWARE_RESTART

-------------------------------------------------------------------------------
12. RECOMMENDED ORDER OF THE NEXT STEPS
-------------------------------------------------------------------------------

  1. [DONE] Measuring print #3: X 49.94 / Y 49.97 / Z 50.06
  2. [DONE] Z-offset: 1.25 accepted, stays
  3. [DONE] X rotation_distance: 40, stays
  4. [DONE] There is no elephant foot - the bottom rim was the SKIRT
            (2 loops). The #3 dimensions are genuine, z_offset 1.25 is
            correct.
  5. [DONE] Hotend PID calibration -> 39.518 / 3.421 / 114.109 (in the cfg)
  6. [DONE] Extruder rotation_distance 33.500 -> 35.845 (in the cfg)
  7. --> NEXT: IdeaMaker Layer Height 0.3 -> 0.2 mm (the main cause of the
            layering), plus resetting Flowrate / XY Size Compensation to
            default now that the 7 % over-extrusion is gone (see section 11)
  8. New cube: evaluate dimensions + corners + layering
  9. Only if still needed: Pressure Advance tuning tower (section 7)
 10. 100 mm test bar -> offset or shrinkage? (section 3)
 11. Final verification cube

THE DIMENSIONAL CALIBRATION IS PRACTICALLY CLOSED - all three axes are
below 0.1 mm. The remaining work is about SURFACE QUALITY, not dimensions.

IMPORTANT: always change ONLY ONE thing between two tests, otherwise you
cannot tell which modification did what.

===============================================================================
END
===============================================================================

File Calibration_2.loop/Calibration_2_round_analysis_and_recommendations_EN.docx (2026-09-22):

Calibration - 2 . circle: analysis offers

Anet A 8 Plus · Raspberry Pi 3 · BIGTREETECH SKR 2 · Klipper / Mainsail · IdeaMaker 5.5 . 0.8810

Model: Flow_Calibration_Cube_0.4_mm.stl (50 mm 50 mm 50 mm) Filament: [Raise3D] Premium PLA 1.75 mm

Measurement summary

Axis | 3 measurement | Average | Deviation | error %
X | 49.76 / 49.74 / 49.69 | 49.730 | - 0.270 mm | - 0.54 %
Y | 49.82 / 49.85 / 49.84 | 49.837 | - 0.163 mm | - 0.33 %
Z | 49.78 / 49.80 / 49.74 | 49.773 | - 0.227 mm | - 0.45 %

The G-code side is correct: bounding box exactly X100 150 / Y100 150; the outer wall course runs from 100.200 to 149.800 (0.2 = half extrusion width), and the last layer is ;LAYER:199 / ;Z:50.000. Thus, the slicer targets exactly 50.000 mm the deficiency is physical, not a G-code error.

Stepper motor step count almost certainly NOT is the wrong one

Steps:

1 . The configurations of X and Y are identical ( rotation_distance : 40 , microsteps : 16 → 80 steps/mm), yet 0.107 mm - rel differ from each other. A step count- error would screw both equally.

2. Z uses a completely different drive (T8 spindle, rotation_distance: 8 400 step/mm), with an error near 0.45%. Two independent drivetrains cannot coincidentally be identical in proportion.

3 . The gotten value resulting from the rotation_distance : 40 geometry ( GT2 belt 2 mm division × 20 tooth ).errors are discrete: if 16 toothed pulley is were , it would be − 20 % were , not − 0.5 % . The same applies for Z: the rise of 8 mm.

4 . All three shrink 0.3 – 0.55 % – this is the textbook thermal expansion shrink of PLA ( 0.3 – 0.5 % ).

In short, it's material shrinkage + slight underextrusion, not step count error.

The fan issue is clarified

Based on G- code, the fan not went at maximum :

• ; LAYER : 1 → M106 S64 = 25 %

• ; LAYER : 3 → M106 S153 = 60 %

• then 60 % , no more M106 until the end of printing

So 3 . for layer a there is a jump from 25 % to 60 % – this is caused the sense of “maximumra went”. not Klipper - error , than is the cooling ramp for IdeaMaker. For the however 190 °C nozzle, the sudden 60 % cooling too much : destroy the layer adhesion and increases the shrinkage stress.

Offered New Settings

IdeaMaker - the main fixes

Setup | Current | Offered | Why
Flow / Filament Compensation # 1 | 94 % | 100 % | The extruder is calibrated (rotation_distance: 35.845), so 94% would be double compensation. It produces a narrower wall (0.376 instead of 0.4), which removes approximately 0.012 mm.
Nozzle temperature | 190 °C | 200 – 205 °C | Raise3D Premium PLA factory recommendation approx. 205 °C. 190 °C + 60 % cooling gives low layer adhesion.
bed temperature | 50 °C | 60 °C | better grip, less bottom warp.
Fan | L 1: 25 % , L3 : 60 % | L1: 0%, then ramp from L6 to L8 to a maximum of 50%. | Instead of a sudden jump, use gradual cooling less shrinkage stress.

Size compensation

this only finalize after B- test, but the initial values are:

• X: 50 / 49.730 = 100.54 %

• Y: 50 / 49.837 = 100.33 %

• Z: 50 / 49.773 = 100.46 %

Set this in the slicer ( Shrinkage Compensation – Scale Factor ), not ` rotation_distance `- ben . If you burn into the machine, then PETG / ABS / TPU when printing (other shrinkage) again wrong , and destroy the layer height and also probe

Since the X/Y difference (0.11 mm) is greater than the measurement standard deviation, it would be worth checking the X belt tension and pulley grub screw. X is the worst axis, and on the A8 Plus the X belt is the most flexible element.

printer. cfg – amit I would definitely fix it

These not they talk about size problem but real errors are Configuration_Files_Mainsail_Klipper / printer . In file cfg:

1. The bed range mesh is physically unreachable. The mesh_max coordinates are 280,280; with the probe offsets (x_offset: 30, y_offset: 25), the nozzle would need to travel to X=310, Y=305, but position_max is 300. Recommended:

[ bed_mesh ]

mesh_min : 20 , 20

mesh_max : 265 , 265

2 . old remainder is SAVE_CONFIG block : a [ stepper_z ] position_endstop = 0.300 remained , and the is endstop probe : z_virtual_endstop . this delete it.

3. BLTouch Z-offset manual value (z_offset: 1.25); the [bltouch] SAVE_CONFIG block is empty, meaning PROBE_CALIBRATE has never been run. This directly affects the Z dimension and the first layer. Instead of paper: PROBE_CALIBRATE TESTZ ACCEPT SAVE_CONFIG.

4 . ` pressure_advance : 0.05 ` only tipp. This affects the geometry of the sarkok - worth calibrating.

next round

A- test – permanent exclusion of the number of steps (without plastic)

G28

G90

G1 X10 F3000

Mark the nozzle position, then:

G1 X210 F3000

Measure the distance between the two positions with a steel ruler or caliper; 200.00 mm 0.2 mm is expected. The same applies to Y. If it matches, rotation_distance is certainly correct and does not need to be modified.

B-test - proportional or constant error? (This is the key question.)

Print a 100mm × 20mm × 20mm column next to cube.

• If the side of 100 mm is also approx. 0.5 % - kal (approx. 0.5 mm ) short → shrinkage → proportional Scale compensation to correct .

- If every size is short by the same amount (approximately 0.25 mm), regardless of length extrusion-width / flow error XY Size Compensation (horizontal expansion) is correct.

Only not can be decided from the 50 mm cube, so given is the misleading result of the first round.

Only then , if A- test is really showed a machine error

The values would be These - but based on the results bellow :

# only if mechanical problem verified!

[ stepper_x ] rotation_distance : 39.784

[ stepper_y ] rotation_distance : 39.869

[ stepper_z ] rotation_distance : 7.9637

Where is 94% set?

It is not in the template Advanced Settings. Screenshot 15 covers the entire tab, and neither location contains 94%.

A ; Filament Compensation # 1 : 94.000 and M221 T0 S94 . 00 a comes from filament definition, not from slicing template. The header of the G-code tells you which one:

; Filament Name # 1 : [ Raise3D ] Premium PLA 1.75mm

; Filament Compensation # 1 : 94.000

This is [Raise3D] Premium PLA 1.75 mm, stored in the filament named PLA; the Diameter, Density, and Type fields are next to it.

Set to 100 %

IdeaMaker main window → right-hand panel Filament drop-down next to the edit ( gear ) icon , or in the top menu Printer → Filament Settings …

In the window that opens, select [ Raise3D ] Premium PLA 1.75mm filamentet , and rewrite the field Compensation / Filament Compensation 94 → 100 .

Check after reslicing - the G- code header should read this:

; Filament Compensation # 1 : 100.000

M221 T0 S100 . 00

two flow layers are multiplied together

I saw Amit on the Quality tab (this is the second layer, per feature):

Flowrate | Value
Outer Shell Flowrate | 100.0 %
Inner Shell Flowrate | 90.0 %
Infill Flowrate | 90.0 %
Base / Solid Fill Flowrate | 95.0 %
Top / Bottom Surface | 120.0 %

The actual amount of material = Filament Compensation feature Flowrate. For the external wall (which defines the size), it is currently 94% 100% = 94%. Therefore, the size-reducing under-extrusion comes entirely from the 94% filament setting; setting it to 100% cancels exactly this effect.

For # 2 : 90.000 a second extruder filament , print no matters.

offered settings

Quality tab, right side - "Shrinkage Compensation"

currently 100.00 % :

Scale Factor X: 100.54

Scale Factor Y: 100.33

Scale Factor Z: 100.46

This shrinkage compensation is correct place – not to rotation_distance. left-hand “ Dimensional Compensation → XY Size Compensation for Contours ” however constant mm offset - then use if B- test constant, showed not proportional error.

Cooling tab - “ Fan Control ” lista

Currently:

Layer | Fan Speed
2 | 25
4 | 60

The G-code is based on 0; LAYER: numbering explains why M106 S64 appears for layer 1 and M106 S153 for layer 3, so it matches.

Recommended softer ramp:

Layer | Fan Speed
2 | 20
5 | 35
8 | 50

Temperature tab

• Heated Bed Temperature : 50 → 60 °C

• Primary Extruder : 190 → 200 – 205 °C

Order keep this in mind

First set flow to 100 print the cube again before entering Scale Factor - okat - otherwise you would also compensate for the flow improvement and miss the mark.

1 . Filament Compensation 94 → 100

2 . Fix temperatures and fan ramp

3. PROBE_CALIBRATE + SAVE_CONFIG (instead of paper) the detailed description follows in the next section.

4 . A- teszt (mechanical Step Count Check)

5 . Reprint: 50 mm column cube + 100 × 20 × 20 mm column (B- test )

6 . Only then finalize Shrinkage Compensation Scale Factor

Z- offset calibration step by step

The PROBE_CALIBRATE TESTZ ACCEPT SAVE_CONFIG process in detail.

Preparation

Z- offset is temperature dependent, so do need for operating temperature, with a pure nozzle.

1 . Mainsail → Dashboard → set temperatures (from or console):

M140 S60

M104 S200

M190 S60

M109 S200

2 . While heats , clean the tip of the nozzle (copper brush or tweezers , careful – hot). The attached filament residue directly falsifies the offsetet.

3. Extrude a small amount of filament, then wipe away the ooze. If PLA drips continuously and interferes with the paper test, temporarily reduce the nozzle to M104 S170 during measurement the difference in thermal expansion is negligible (approximately 0.01 mm).

The calibration is menete

Mainsail → Console tab and enter:

G28

PROBE_CALIBRATE

In Klipper :

• measures from BLTouch – the current point

Then move the nozzle to the same point (x_offset: 30 / y_offset: 25), from the head position 150,150 to 120,125 approximately the center of the bed, which is ideal.

• and enters manual measurement mode.

1 . method - Mainsail dialog box (simpler)

After PROBE_CALIBRATE in Mainsail automatikusan appears a Z- offset window + / - buttons ( 0.01 / 0.05 / 0.1 / 1 mm ), as well as ACCEPT and ABORT button . You can also do With this by clicking, type not need a command.

2 . method - TESTZ commands

Place a a normal sheet of paper (approx. 0.1 mm ) under the nozzle and zoom down:

TESTZ Z= -1

TESTZ Z= -0.5

TESTZ Z= -0.1

TESTZ Z= -0.05

If you went over (the paper stricked), go back :

TESTZ Z= +0.05

There is also a halving aid: between the known lower and upper limits, it jumps to the midpoint.

TESTZ Z=-

TESTZ Z=+

The goal: the paper is still just sliding, but you are already pulling with noticeable friction. Don't stuck in.

Completion

ACCEPT

SAVE_CONFIG

• ACCEPT calculates the new z_offset .

• SAVE_CONFIG will enter into the config and restart Klippert (this is normal).

Checking

After reboot, printer.cfg should end with an otherwise empty #*# [bltouch] block containing the value:

#*# [ bltouch ]

#*# z_offset = 1 . xxx

This overrides the manually entered z_offset : 1.25 in the [ bltouch ] section - so you know , that are really completed .

Fine tuning on the first layer

The paper test only is a good place to start. The actual setting is done during printing:

1 . Start a large , single layer test.

2 . During printing, adjust in Mainsail a Z offset + / - buttons ( or SET_GCODE_OFFSET Z_ADJUST = -0.01 MOVE = 1 ) until the first layer is nicely connected, slightly flattened.

3 . If ok , burn in the found value:

Z_OFFSET_APPLY_PROBE

SAVE_CONFIG

This adds live offsetet to probe z_offset - hez, so the next time is already good.

Two important comments

Correction to the previous statement: I wrote above azt from nose #*# [ stepper_z ] position_endstop = 0.300 s , that "collides" with the virtual endstoppal. More precisely: probe : z_virtual_endstop when using Klipper this the field simply figyelmen outside leaves , not cousing error. Only misleading residue - safely can be deleted but not is urgent.

However, bed mesh calibration is urgent: if you run BED_MESH_CALIBRATE after the Z-offset, the current mesh_max: 280,280 would cause the nozzle to move out of bounds, because it would need to travel to X=310 / Y=305, beyond position_max: 300. This must first be corrected to 265,265.

BLTouch and bed mesh calibration

Complete this calibration before the first print. The BLTouch Z offset defines the vertical distance between the nozzle and the probe trigger point. The bed mesh maps small height variations across the build plate.

1. Preparation and safety

1. Clean the nozzle and build plate. Do not leave plastic on the nozzle tip.

2. Make sure the BLTouch is firmly mounted, its pin moves freely, and no cable can snag.

3. Turn on the printer and open the Mainsail Console.

4. Keep Emergency Stop within reach. If Z moves down and the BLTouch does not stop it, press Emergency Stop immediately.

2. Test the BLTouch

Run these commands one at a time in the Console:

BLTOUCH_DEBUG COMMAND=reset

BLTOUCH_DEBUG COMMAND=pin_down

BLTOUCH_DEBUG COMMAND=pin_up

The pin must deploy and retract. Next, deploy the pin and gently push it upward by hand:

BLTOUCH_DEBUG COMMAND=pin_down

QUERY_PROBE

With the pin deployed, the result must be open. Push the pin up and run QUERY_PROBE again; the result must be TRIGGERED. If this does not work, do not home the printer. Check the wiring and the sensor_pin/control_pin settings in printer.cfg.

3. Test Z homing

1. Move the printhead so that the BLTouch is above the build plate.

2. Run G28. The printer homes X and Y first, then homes Z near the center of the bed.

3. During the Z movement, gently touch the BLTouch pin. Z must stop immediately. If it does not stop, use Emergency Stop.

4. If the test succeeds, run G28 again and allow the BLTouch to complete Z homing against the bed.

G28

4. Calibrate the BLTouch Z offset

1. Use conditions close to normal printing: heat the bed to the temperature used for the material, then wait a few minutes. Keep the nozzle clean; for a safe paper test, do not leave hot plastic on its tip.

2. Run G28, followed by PROBE_CALIBRATE.

3. Place a sheet of ordinary paper under the nozzle.

4. Move down with TESTZ Z=-1, then TESTZ Z=-0.1. Near the paper, use smaller TESTZ Z=-0.01 steps.

5. If the nozzle moves too low, raise it with TESTZ Z=0.01. The height is correct when the paper still moves but lightly drags against the nozzle.

6. Run ACCEPT. The result is not accepted without this command.

7. Run SAVE_CONFIG. Klipper restarts and automatically saves the z_offset value in the SAVE_CONFIG block at the end of printer.cfg.

G28

PROBE_CALIBRATE

TESTZ Z=-0.1

TESTZ Z=-0.01

ACCEPT

SAVE_CONFIG

Do not edit the SAVE_CONFIG block manually. Pin and offset settings in the normal [bltouch] section of printer.cfg can be edited manually, but Klipper manages the calibrated z_offset value.

5. Calibrate the bed mesh

A bed mesh does not replace mechanical bed leveling. First adjust the bed to be as level as possible, then create the mesh.

1. Heat the bed to the temperature normally used for printing, then wait a few minutes for thermal expansion to stabilize.

2. Run G28.

3. Run BED_MESH_CALIBRATE. With the current printer.cfg settings, the BLTouch measures a 5 x 5 grid, for a total of 25 points.

4. Wait until all measurement points are complete.

5. Run SAVE_CONFIG. Klipper restarts and saves the mesh under the name default.

G28

BED_MESH_CALIBRATE

SAVE_CONFIG

6. Use the saved mesh

BED_MESH_CALIBRATE measures all points only during calibration. For normal printing, load the saved mesh. Add this command to the IdeaMaker Start G-code after G28:

BED_MESH_PROFILE LOAD=default

Important: G28 may clear the active mesh, so the load command must always come after G28.

7. Verification and recalibration

1. Print a first-layer test and make small Z-offset corrections in Mainsail if necessary.

2. After changing the Z offset, save it with SAVE_CONFIG.

3. Repeat PROBE_CALIBRATE after changing the nozzle, hotend, or BLTouch mounting.

4. Create a new bed mesh after adjusting the bed, BLTouch, or printer mechanics, or if first-layer height still varies across the bed.

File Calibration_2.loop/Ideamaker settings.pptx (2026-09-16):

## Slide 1

Layer hight changed to 0,25mm, first layer hight changed to 0,25mm

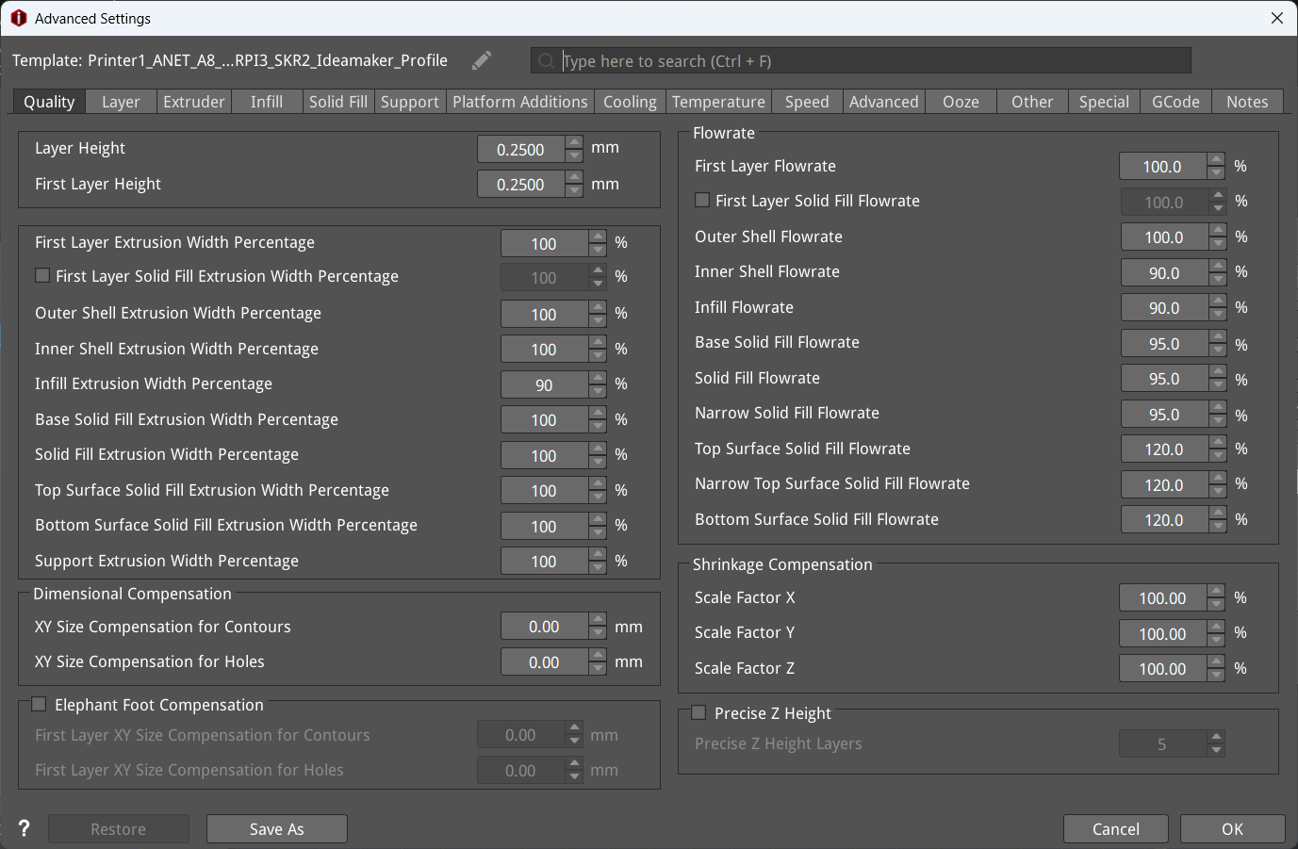
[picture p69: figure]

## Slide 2

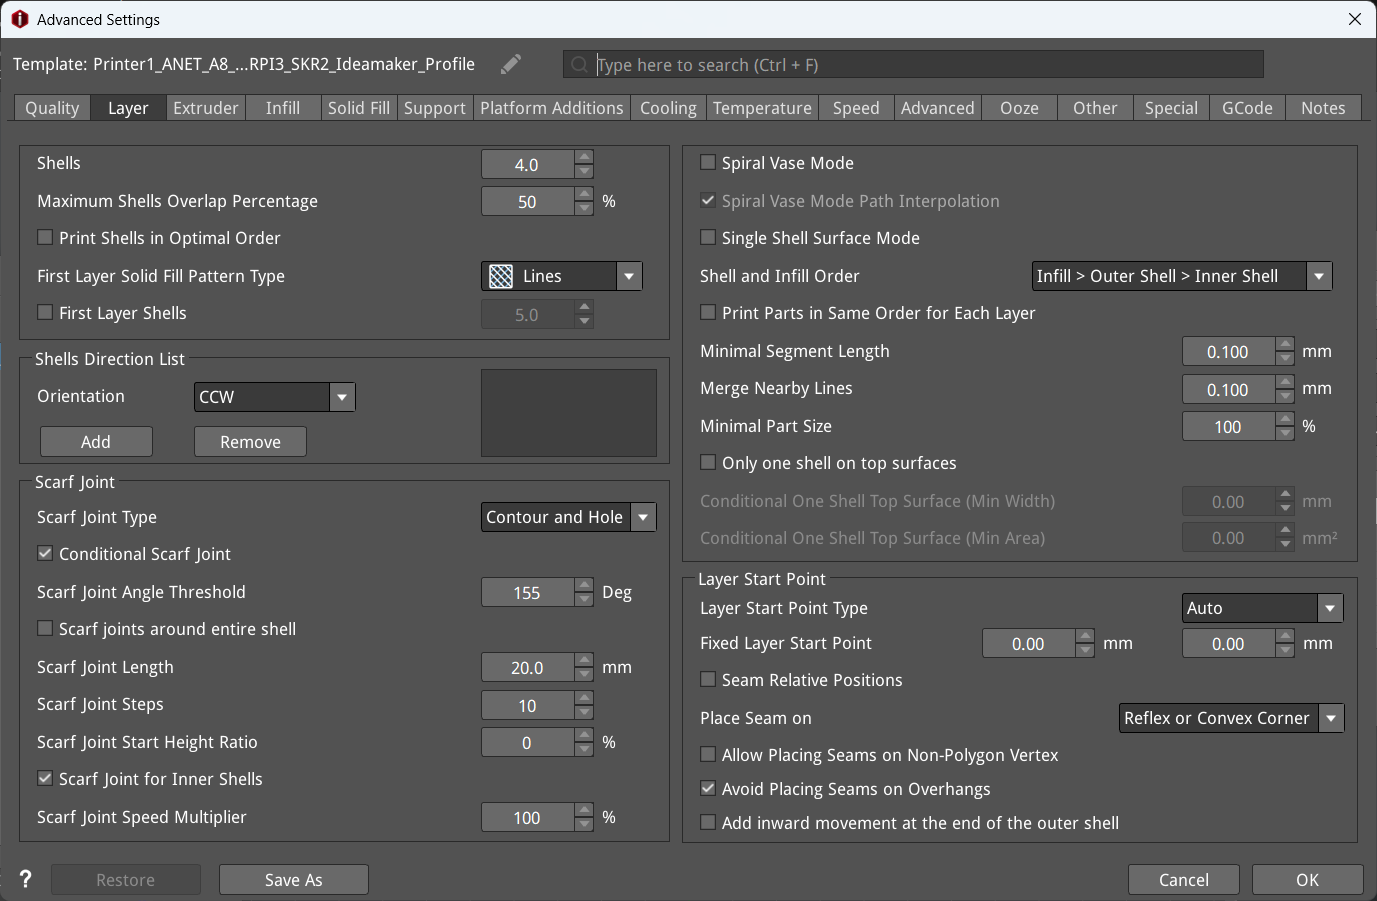
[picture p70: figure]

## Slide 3

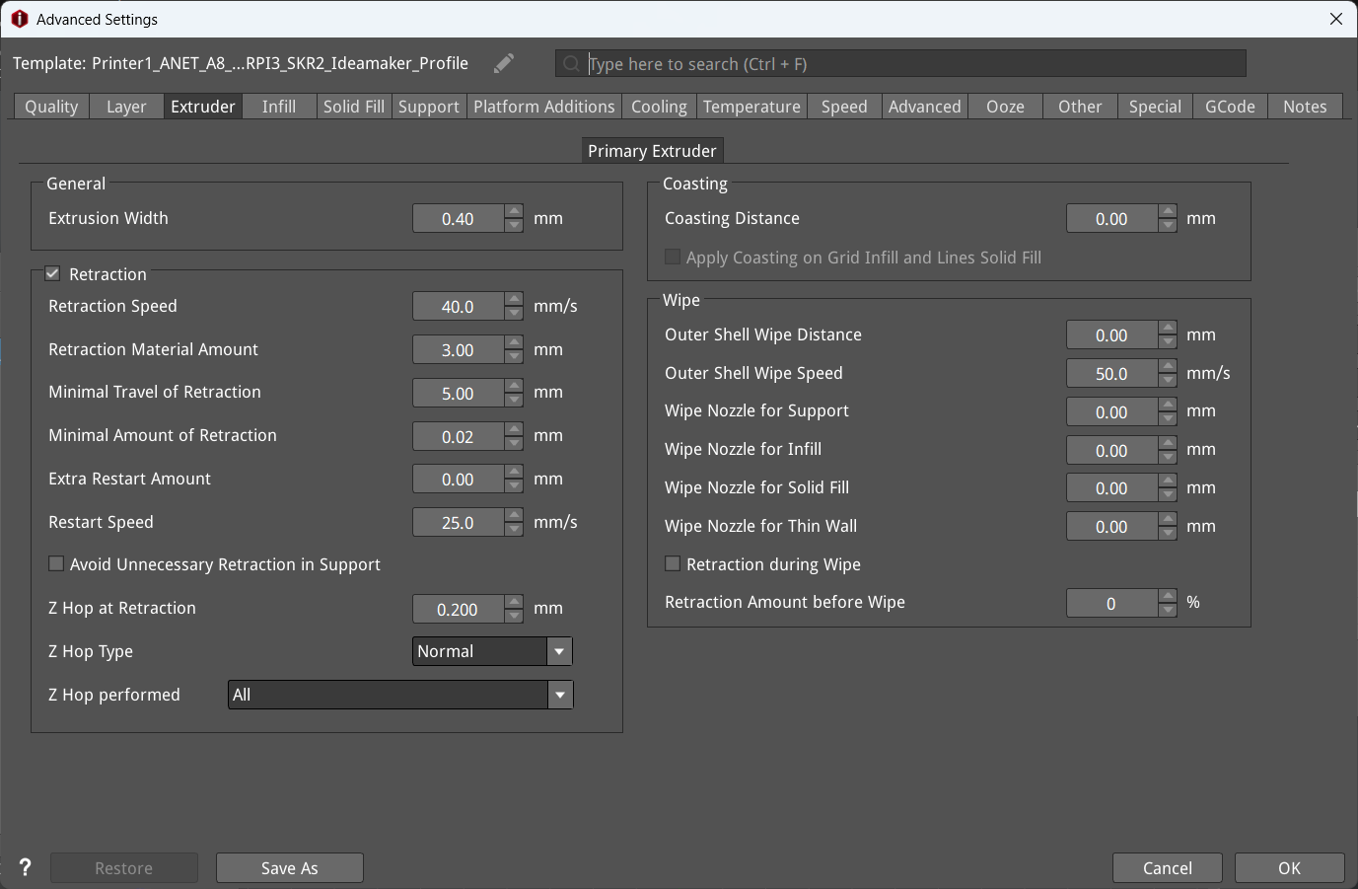
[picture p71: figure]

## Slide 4

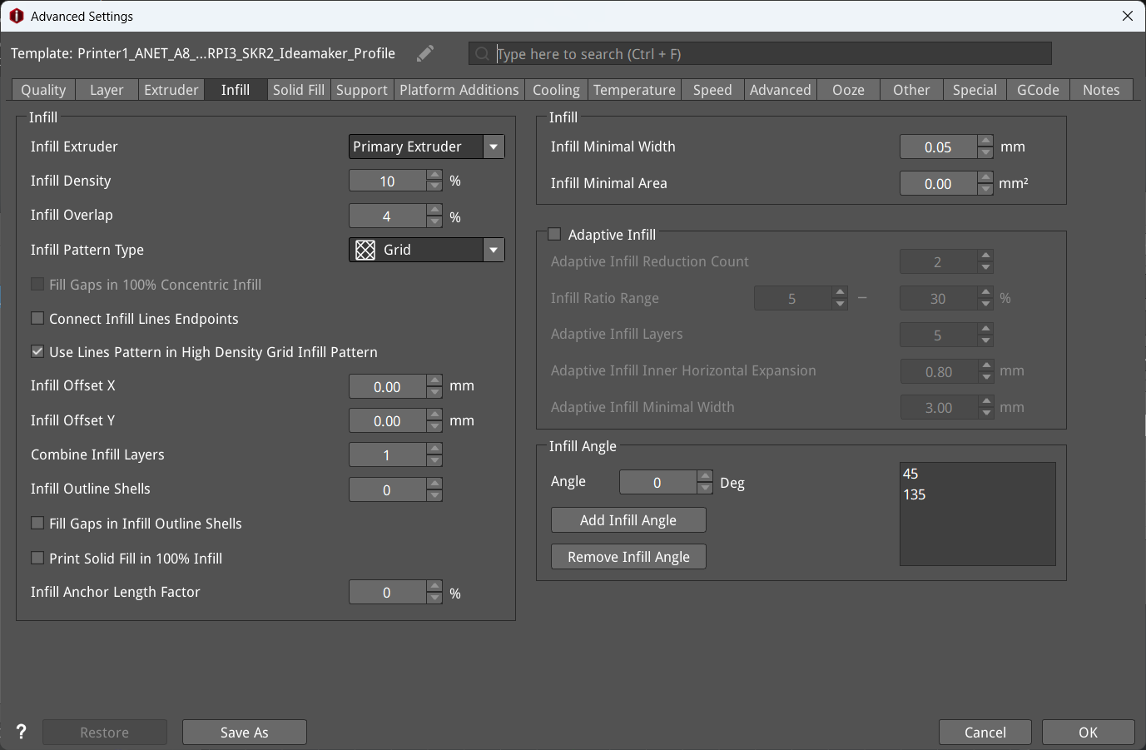
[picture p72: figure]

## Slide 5

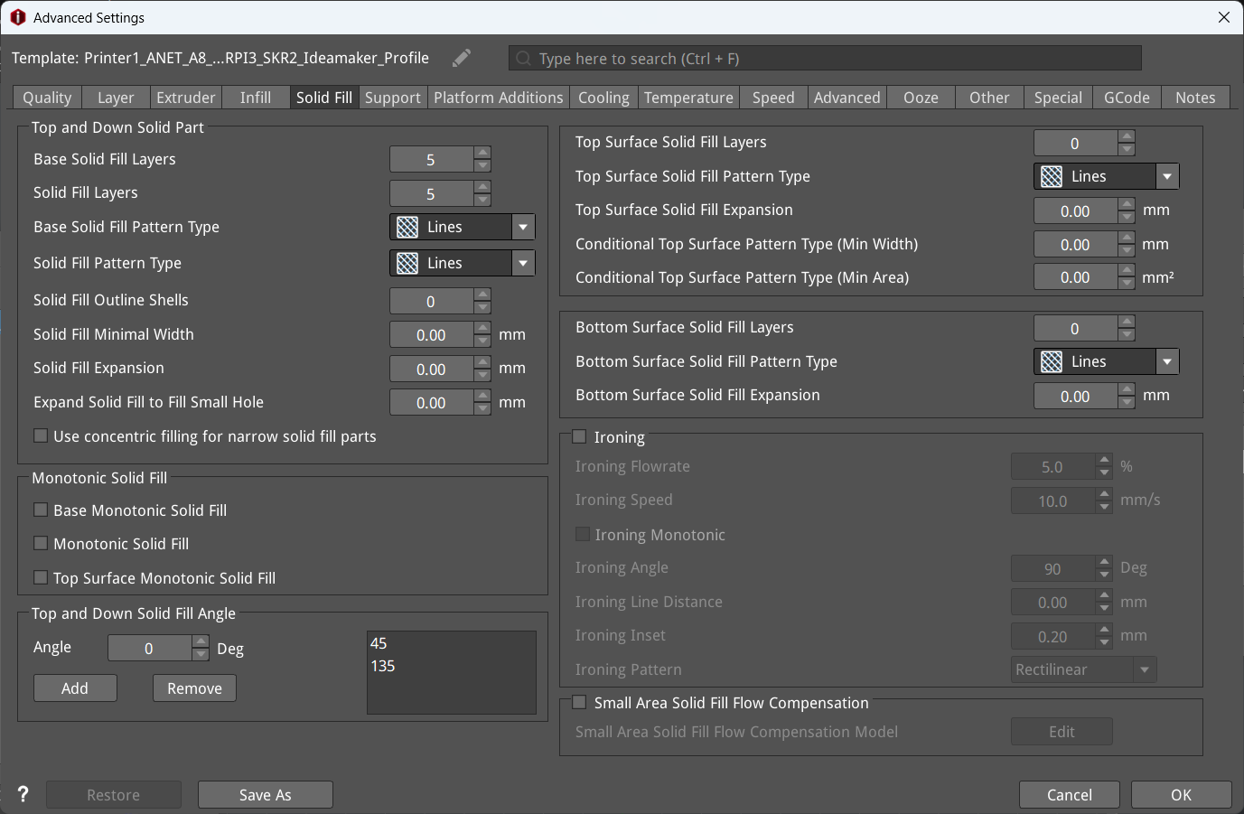
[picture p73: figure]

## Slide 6

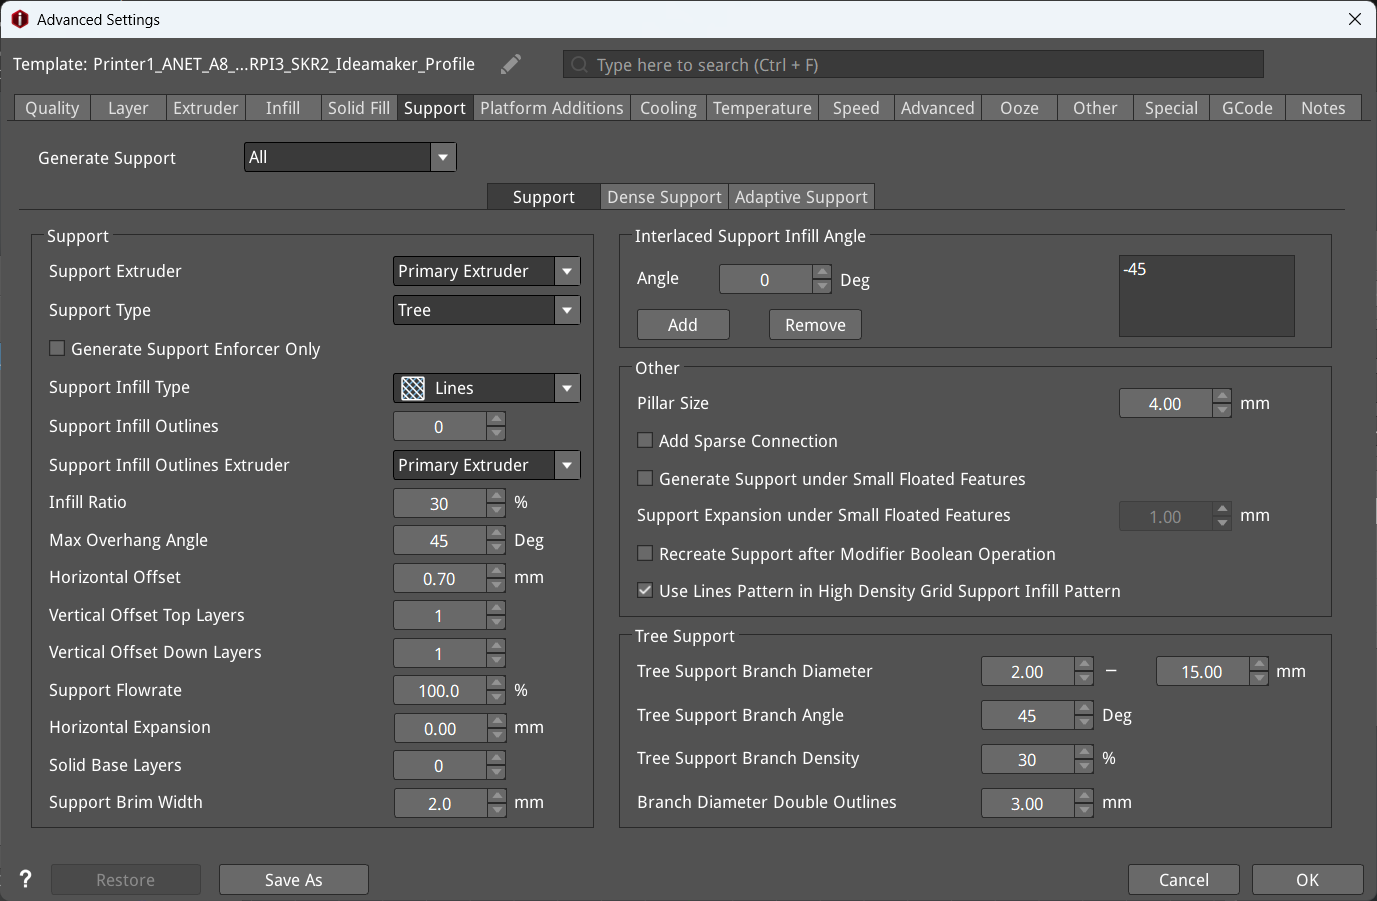
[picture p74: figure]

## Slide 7

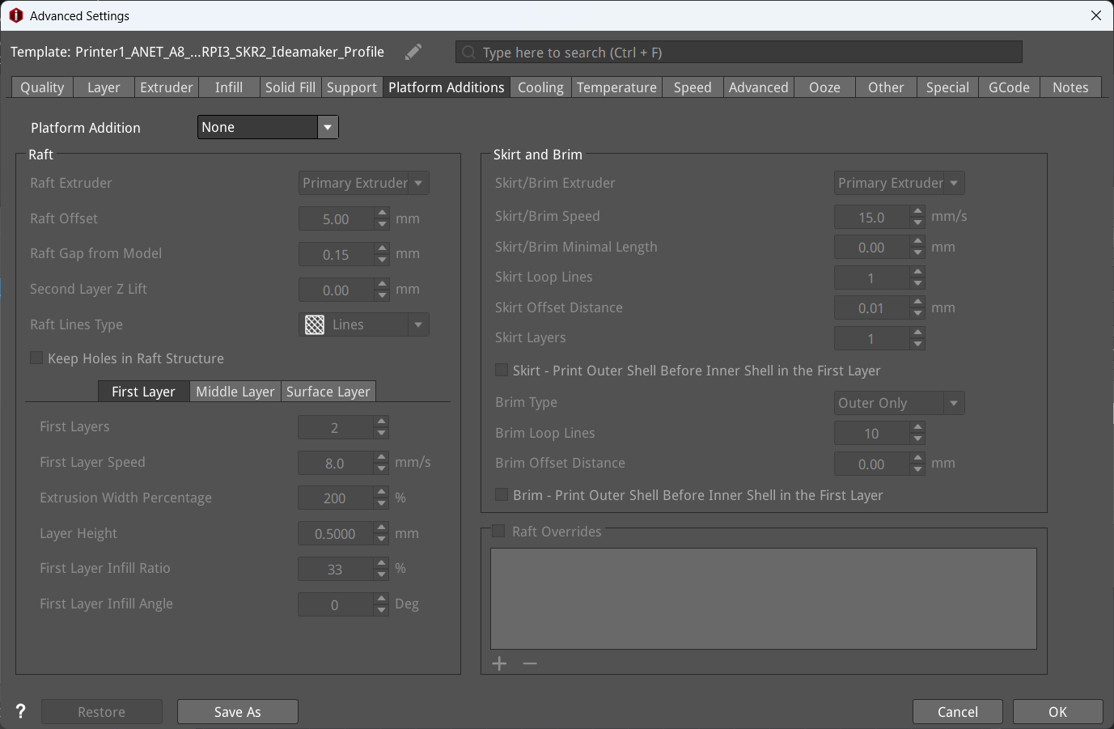
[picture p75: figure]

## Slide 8

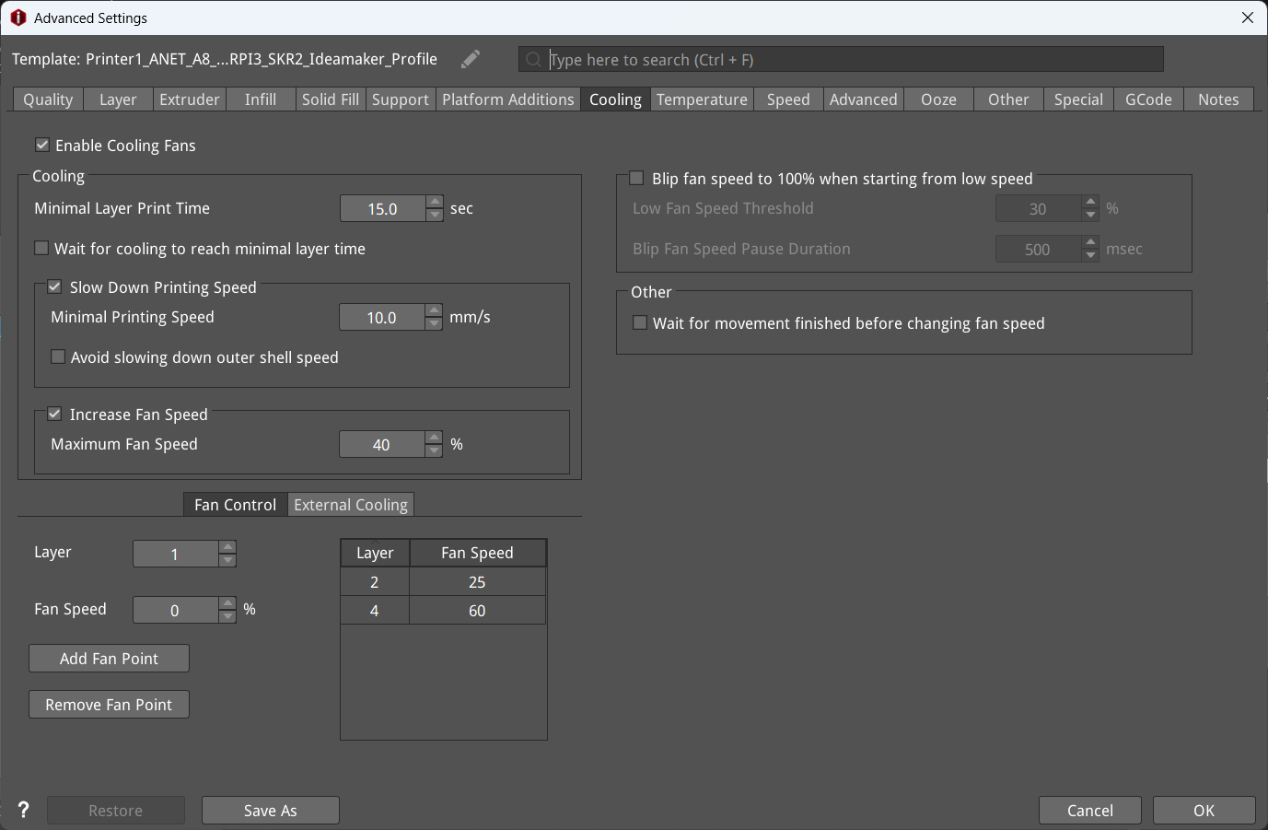
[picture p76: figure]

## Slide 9

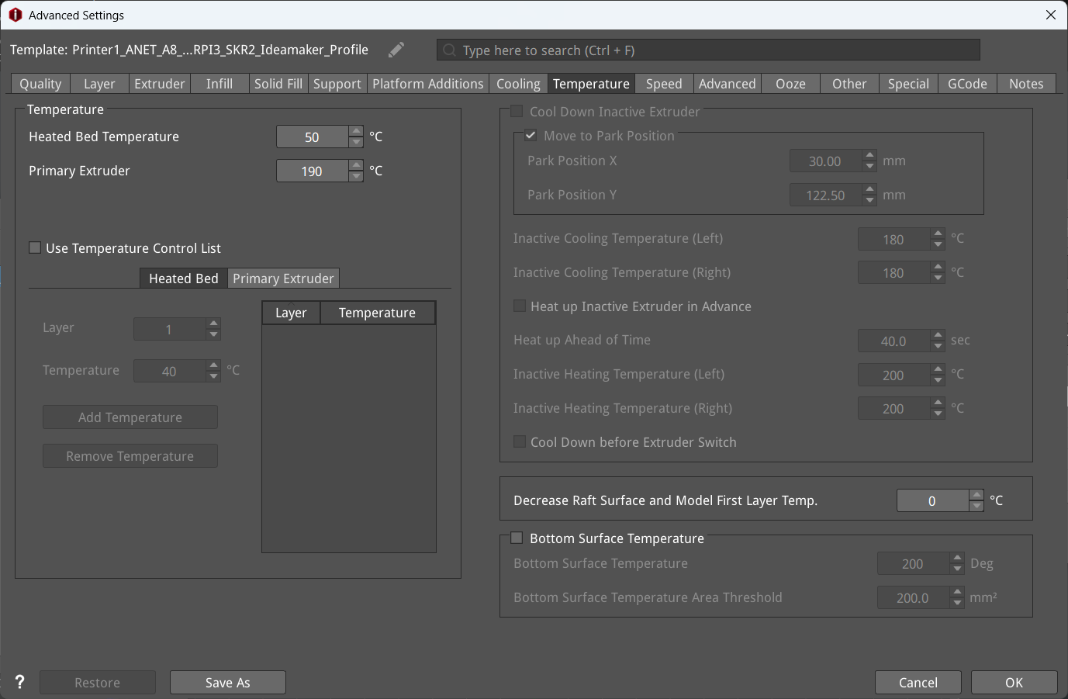
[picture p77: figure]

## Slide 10

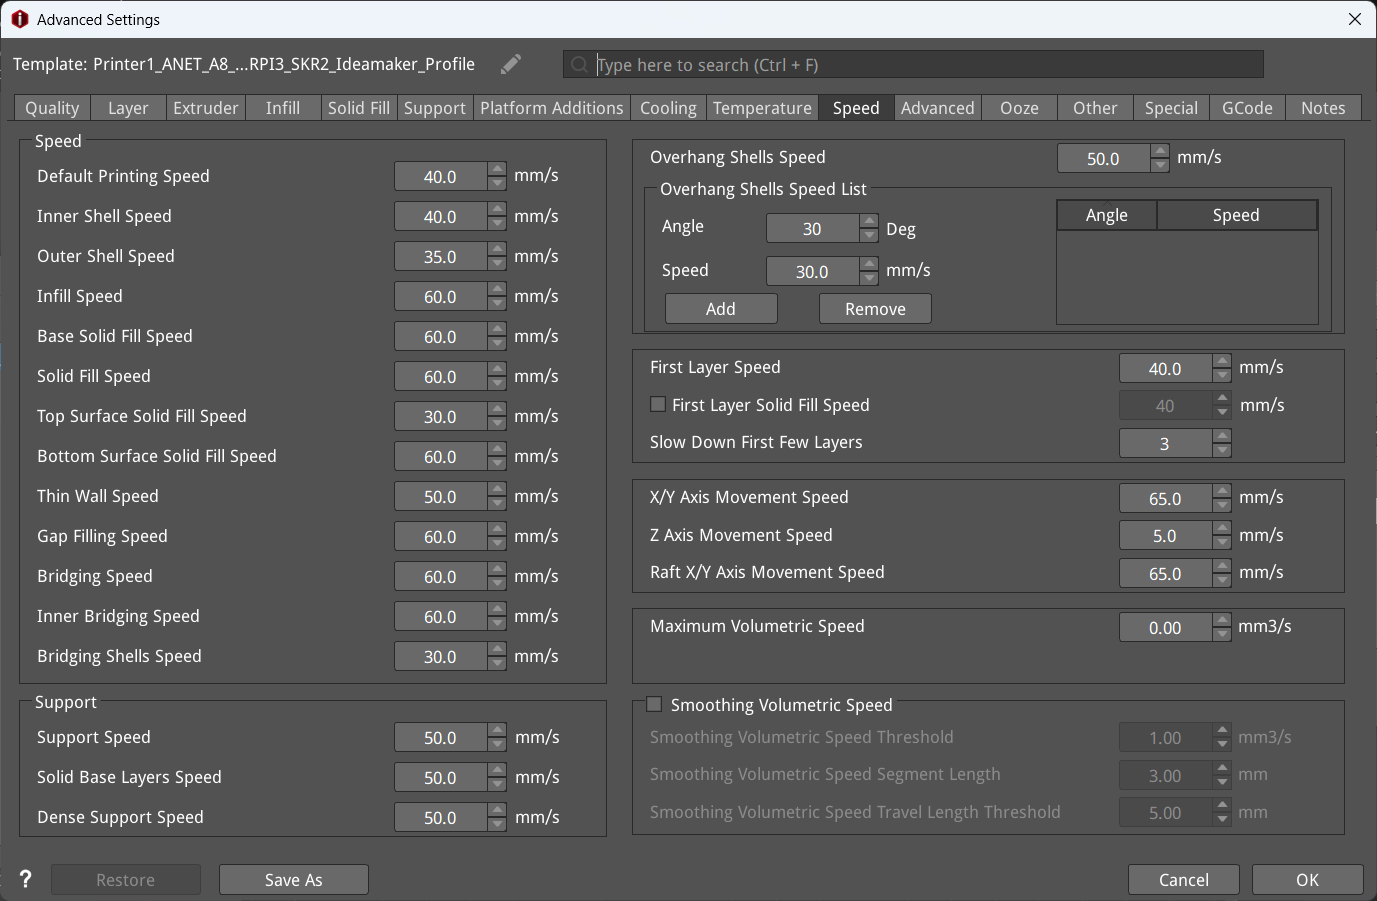
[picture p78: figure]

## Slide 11


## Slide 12


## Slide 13


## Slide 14


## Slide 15


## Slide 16


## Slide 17

X: 49,73mm Y: 49:84mm Z: 49,77mm


X,Y,Z size not correct, quality of the printed modell impoved, less layer shift observed

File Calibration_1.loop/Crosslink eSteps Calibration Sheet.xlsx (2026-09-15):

Crosslink eSteps Calculation Sheet
Print test cube first: | https://www.thingiverse.com/thing:3189377
Guide for X Y and Z calibration: | https://youtu.be/SN9NCn-Dhf8
Guide for extruder calibration: | https://youtu.be/t5aQCftfK1M
Input parameters | Testprint 1 |  |  |  | Testprint 2
Current eSstep values | X | Y | Z | E | X | Y | Z | E
Get with M503 command and read it from the M92 result | 40.00 | 40.00 | 8.00 |  | 39.56 | 39.51 | 8.11 | #DIV/0!
Measured Dimensions | X | Y | Z | E | X | Y | Z | E
 | 20.22 | 20.25 | 19.74
New eStep values | X | Y | Z | E | X | Y | Z | E
Set with M92 command | 39.56 | 39.51 | 8.11 | #DIV/0! | #DIV/0! | #DIV/0! | #DIV/0! | #DIV/0!

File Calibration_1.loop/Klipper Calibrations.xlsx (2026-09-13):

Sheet: INSTRUCTIONS
To Use the Spreadsheet Go to "File" -> "Make a Copy"
You can also try my Klipper Calibration website:
Minilam3DP Klipper Calibration Website: https://minimal3dp.com/ | minimal3dp@gmail.com
Minimal 3Dp on Youtube | Minimal 3DP (https://www.youtube.com/channel/UCM_8Mv-0S1LnnJpRJLjahaw?sub_confirmation=1)
Try My Klipper Calibration Website | Klipper Calibration Website (https://minimal3dp.com/klipper-calibration/)
TABS AT BOTTOM FOR VARIOUS TESTS
↓

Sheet: Extruder Rotation Distance
Extruder Rotation Distance
Video Guide
References: | Rotation distance - Klipper documentation (https://www.klipper3d.org/Rotation_Distance.html)
 | Klipper Extruder Rotation Distance Calculator | 3D Print Beginner (https://3dprintbeginner.com/rotation-distance-calculator/)
Legend: |  |  | Variables:
 | DO NOT EDIT |  | Full Steps Per Rotation | 1.8 Stepper | 200
 | Edit to Suit |  | Full Steps Per Rotation | .9 Stepper | 400
 | User Input |  |  | Micro Steps | 32
E-Steps and Rotation Distance Calculations
Rotation Distance = | Full Steps Per Rotation * | Micro Steps / | E Steps
16 | 200 | 32 | 400
E-Steps = | Full Steps Per Rotation * | Micro Steps / | Rotation Distance
800 | 200 | 32 | 8
Measure and Trim | Rotation distance - Klipper documentation (https://www.klipper3d.org/Rotation_Distance.html)
initial_mark_distance | 70 | mm
requested_extrude_distance | 50 | mm
Console Commands:
 | G91
 | G1 E50 F60 | E## = requested_extrude_distance
actual_extrude_distance = | initial_mark_distance | - subsequent_mark_distance
49.51 | 70 | 20.49
Rotation Distance = | previous_rotation_distance | * actual_extrude_distance | / requested_extrude_distance
24.235 | 24.475 | 49.51 | 50

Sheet: Flow Calibration
Flow Calibration | Not Recommended
Video Guide
References: | https://3dprintbeginner.com/flow-rate-calibration/
 | https://3dprinterly.com/how-to-calibrate-your-extruder-e-steps-flow-rate/
Legend:
 | DO NOT EDIT
 | Edit to Suit
 | User Input
Slicer Settings:
Layer Height | 0.2
Perimeters | 2
Line Width | 0.5
Print Thin Walls | Off
Top Layer | 0
Bottom Layer | 1
Infill | 0%
Cube STL File: | Flow_Cube.stl (https://drive.google.com/file/d/11vJEoea94jWu8c0bYwK1tcJ92S1TD9wj/view?usp=sharing)
Steps:
1 | Print Cube with Settings Above
2 | Measure the top of all 4 sides and place values below
3 | Update Flow in Slicer with "FLOW" Value
Nozzle Diameter | 0.4
Measure 1 | 0.930
Measure 2 | 0.950
Measure 3 | 0.950
Measure 4 | 0.960
Average | 0.9475
FLOW Value | 105.541 | %

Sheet: OrcaSlicer Flow Calibration
Orca SlicerFlow | Recommended
Calibration
Video Guide
References: | https://3dprintbeginner.com/flow-rate-calibration/
 | https://3dprinterly.com/how-to-calibrate-your-extruder-e-steps-flow-rate/
Legend:
 | DO NOT EDIT
 | Edit to Suit
 | User Input
Steps:
1 | Orca Slicer -> Calibration -> Flow Rate -> Pass 1
2 | Feel each "Slide" and determine the Smoothest
3 | Update Values Below
Pass 1
Old Flow Rate | 1
Pass 1 Slide Value | -10.000
Pass 1 FLOW Value | 0.900
4 | Complete Pass 2
Pass 2
Pass 1 Flow Rate | 0.900
Pass 2 Slide Value | -1.000
New FLOW Value | 0.891
5 | Use Pass 2 Flow Rate in Slicer

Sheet: Run Current
Run Current for TMC2208/2209
Video Guide
References: | https://docs.vorondesign.com/community/howto/120decibell/calculating_driver_current.html
Legend:
 | DO NOT EDIT
 | Edit to Suit
 | User Input
Peak Current | 1.500 | See Motor Spec Sheet
RMS Factor | 0.707 | See Reference
Run Current | 1 | Update TMC Section of Printer.cfg

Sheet: Pressure Advance
Pressure Advance
Video Guide
References: | https://www.klipper3d.org/Pressure_Advance.html
Legend:
 | DO NOT EDIT
 | Edit to Suit
 | User Input
Nozzle Diameter | 0.4
Layer Height | 0.3
Infill | 0
COMANDS:
Setup | SET_VELOCITY_LIMIT SQUARE_CORNER_VELOCITY=1 ACCEL=500
Direct Drive | TUNING_TOWER COMMAND=SET_PRESSURE_ADVANCE PARAMETER=ADVANCE START=0 FACTOR=.005
Bowden | TUNING_TOWER COMMAND=SET_PRESSURE_ADVANCE PARAMETER=ADVANCE START=0 FACTOR=.020
pressure_advance = <start> + <measured_height> * <factor>
Square Tower | https://www.klipper3d.org/prints/square_tower.stl
Start | 0 | Based on Commands above
Direct Drive Factor | 0.005 | Based on Commands above
Bowden Factor | 0.02 | Based on Commands above
Measured Height | 12.29
Direct Drive Pressure Advance | 0.06145 | Use for Direct Drive
Bowden Pressure Advance | 0.2458 | Use for Bowden
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

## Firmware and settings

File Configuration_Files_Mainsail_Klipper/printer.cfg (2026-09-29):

# This file contains common pin mappings for the BigTreeTech SKR 2.
# To use this config, the firmware should be compiled for the
# STM32F407 with a "32KiB bootloader".

# In newer versions of this board shipped in late 2021 the STM32F429
# is used, if this is the case compile for this with a "32KiB bootloader"
# You will need to check the chip on your board to identify which you have.
#
# The "make flash" command does not work on the SKR 2. Instead,
# after running "make", copy the generated "out/klipper.bin" file to a
# file named "firmware.bin" on an SD card and then restart the SKR 2
# with that SD card.

# See docs/Config_Reference.md for a description of parameters.

# Note: The initial revision of this board has a flaw that can cause
# damage to itself and other boards. Be sure to verify the board is
# not impacted by this flaw before using it.

##################################################################   PRINTER_1   Raspberry 3b+ & SKR2   ##############################################################

[include mainsail.cfg]

[mcu]
serial: /dev/serial/by-id/usb-Klipper_stm32f407xx_2D0027000C47393437303337-if00

[stepper_x]
step_pin: PE2
dir_pin: !PE1
enable_pin: !PE3
microsteps: 16
rotation_distance: 40
endstop_pin: ^!PC1
position_endstop: 0
position_max: 300
homing_speed: 50

[stepper_y]
step_pin: PD5
dir_pin: !PD4
enable_pin: !PD6
microsteps: 16
rotation_distance: 40
endstop_pin: ^!PC3
position_endstop: 0
position_max: 300
homing_speed: 50

[stepper_z]
step_pin: PA15
dir_pin: !PA8
enable_pin: !PD1
microsteps: 16
rotation_distance: 8
endstop_pin: probe:z_virtual_endstop
#endstop_pin: ^!PC0
#position_endstop: 0.5
position_max: 300
#position_min: -0.5

[extruder]
step_pin: PD15
dir_pin: PD14
enable_pin: !PC7
microsteps: 16
rotation_distance: 35.845
nozzle_diameter: 0.400
filament_diameter: 1.750
heater_pin: PB4
sensor_type: EPCOS 100K B57560G104F
sensor_pin: PA2
#control: pid
#pid_Kp: 39.518
#pid_Ki: 3.421
#pid_Kd: 114.109
min_temp: 10
max_temp: 250
# Kell a 100 mm-es extruder kalibraciohoz (alapertek csak 50 mm)
max_extrude_only_distance: 150
# Sarok-megfolyas ellen. Direct drive kiindulas ~0.03-0.08, Bowden ~0.4-0.8.
# Kalibralas utan (SET_PRESSURE_ADVANCE teszt) ird at!
pressure_advance: 0.05
pressure_advance_smooth_time: 0.040

#[extruder1]
#step_pin: PD11
#dir_pin: PD10
#enable_pin: !PD13
#heater_pin: PB4
#sensor_pin: PA3
#...

[heater_bed]
heater_pin: PB3
sensor_type: Generic 3950
sensor_pin: PA1
#control: watermark
min_temp: 10
max_temp: 130

#[verify_heater heater_bed]
#max_error: 120
#check_gain_time: 90
#hysteresis: 10
#heating_gain: 1

[fan]
pin: PB7

[heater_fan fan1]
pin: PB6

[heater_fan fan2]
pin: PB5

# Due to BTT implementing a Marlin-specific safety feature,
# "anti-reversal stepper protection", this pin needs pulling
# high to pass power to stepper drivers and most FETs

[output_pin motor_power]
pin: PC13
value: 1

[printer]
kinematics: cartesian
max_velocity: 300
# Anet A8 Plus akrilvazhoz a 3000 sok -> ringing es sarok-hiba
max_accel: 1500
square_corner_velocity: 5.0
max_z_velocity: 5
max_z_accel: 100

[bltouch]
sensor_pin: ^PE4  
control_pin: PE5
pin_move_time: 0.7
x_offset: -30
y_offset: -25
#z_offset: 1.036

samples: 2
samples_result: average
samples_tolerance: 0.05
samples_tolerance_retries: 3

[safe_z_home]
home_xy_position: 150,150   # bed közepe (300x300-nál ez tökéletes)
speed: 20
z_hop: 10
z_hop_speed: 5

[bed_mesh]
mesh_min: 25, 25
mesh_max: 255, 255
probe_count: 5,5
algorithm: bicubic
speed: 80
horizontal_move_z: 5
fade_start: 1
fade_end: 10

########################################
# EXP1 / EXP2 (display) pins
########################################

[board_pins]
aliases:
    # EXP1 header
    EXP1_1=PC5, EXP1_3=PB1, EXP1_5=PE10, EXP1_7=PE12, EXP1_9=<GND>,
    EXP1_2=PB0, EXP1_4=PE9, EXP1_6=PE11, EXP1_8=PE13, EXP1_10=<5V>,
    # EXP2 header
    EXP2_1=PA6, EXP2_3=PE7, EXP2_5=PB2, EXP2_7=PC4,   EXP2_9=<GND>,
    EXP2_2=PA5, EXP2_4=PA4, EXP2_6=PA7, EXP2_8=<RST>, EXP2_10=<NC>

# See the sample-lcd.cfg file for definitions of common LCD displays.

########################################
# TMC2209 configuration
########################################

[tmc2209 stepper_x]
uart_pin: PE0
run_current: 0.800
#diag_pin:

[tmc2209 stepper_y]
uart_pin: PD3
run_current: 0.800
#diag_pin:

[tmc2209 stepper_z]
uart_pin: PD0
run_current: 0.800
#diag_pin:

[tmc2209 extruder]
uart_pin: PC6
run_current: 0.600
#diag_pin:

#[tmc2209 extruder1]
#uart_pin: PD12
#run_current: 0.600
#diag_pin:

#*# <---------------------- SAVE_CONFIG ---------------------->
#*# DO NOT EDIT THIS BLOCK OR BELOW. The contents are auto-generated.
#*#
#*# [stepper_z]
#*# position_endstop = 0.300
#*#
#*# [heater_bed]
#*# control = pid
#*# pid_kp = 66.092
#*# pid_ki = 1.270
#*# pid_kd = 860.028
#*#
#*# [bltouch]
#*# z_offset = 1.151
#*#
#*# [extruder]
#*# control = pid
#*# pid_kp = 39.518
#*# pid_ki = 3.421
#*# pid_kd = 114.109
#*#
#*# [bed_mesh default]
#*# version = 1
#*# points =
#*# 	  -0.006250, -0.022500, -0.063750, -0.145000, -0.322500
#*# 	  -0.055000, -0.007500, -0.016250, -0.108750, -0.223750
#*# 	  -0.108750, -0.013750, 0.012500, -0.016250, -0.131250
#*# 	  -0.152500, -0.043750, 0.007500, -0.010000, -0.087500
#*# 	  -0.190000, -0.041250, 0.027500, 0.048750, 0.007500
#*# x_count = 5
#*# y_count = 5
#*# mesh_x_pps = 2
#*# mesh_y_pps = 2
#*# algo = bicubic
#*# tension = 0.2
#*# min_x = 25.0
#*# max_x = 255.0
#*# min_y = 25.0
#*# max_y = 255.0

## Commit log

2025-04-20 STL files
    [130%_Toshiba_Távirányító.010.stl, 20240427_double_values_square_calibration.stl, 25mm_cube.stl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]
2025-04-29 rail end cap
2025-07-31 bag clip
    [clip_bag_02.stl, clip_bag_03.stl, clip_bag_03_hook.stl]
2025-08-06 bag clip 10cm
2025-10-17 p1 halter
    [sensor_halter_RA.stl]
2025-10-19 alátét
    [Washer_Hole.stl]
2025-10-31 Calibration cube
2025-12-06 circuit braker fill
    [Breaker_Filler_Plate_-_Schneider_-_1-UP.stl, Breaker_Filler_Plate_-_Schneider_-_2-UP.stl, Breaker_Filler_Plate_-_Schneider_-_3-UP.stl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]
2026-02-02 Electric holder parts
    [Tape_8_3MF.3mf, Wago+221-420 (1).3mf, Wago+221-420.3mf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]
2026-02-05 Cable, cr7,jesus
2026-02-05 external mosfet built
    extruder heater pin to PB4
    bed heater pin to PB3
    [printer.cfg]
2026-02-10 hole cup, cal cube
2026-02-12 Dani hole cap
    [hole_cap_mid_27.STL, hole_cap_mid_29.5.STL]
2026-02-15 hole cap
2026-09-12 3D touch config
    [printer.cfg]
2026-09-13 calibration cube, and current profile presentation
    [0.20mm-nozzle-0.40mm-walls-humebeam-flow-calibration-cube.stl, Klipper Calibrations.xlsx, Pz_xyz_calibration_cube_v1.stl]
2026-09-13 profile change
    [printer.cfg]
2026-09-14 Calibration cube hollow
    [Calibration_hollow_cube.stl]
2026-09-14 calibration cube rotated with 45deg
2026-09-14 calibration cube 45deg rot hollow
2026-09-14 p1 calibration cube 45rot
2026-09-14 Revise README for Anet A8 Plus Klipper conversion
    Updated the README to reflect the conversion of Printer #1 from Marlin + OctoPrint to Klipper + Mainsail, including detailed project background, system architecture, remote operation, hardware specif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
2026-09-15 Create Crosslink eSteps Calibration Sheet.xlsx
    [Crosslink eSteps Calibration Sheet.xlsx]
2026-09-15 remove threaded bracing rods, set layer high to 0,25mm, bed calibration with paper
    [0.20mm-nozzle-0.40mm-walls-humebeam-flow-calibration-cube.stl, Calibration_hollow_cube.stl, Crosslink eSteps Calibration Sheet.xlsx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]
2026-09-16 Calibration loop 2 -> 50x50x50mm cube
    X: 49,73mm
    Y: 49:84mm
    Z: 49,77mm
    [Calibration cube measured X Y Z size.xlsx]
2026-09-16 Ideamaker settings pptx
    [Calibration cube measured X Y Z size.xlsx]
2026-09-21 calibration loop 2 files
2026-09-22 calibration loop 2 and printer.cfg
    [printer.cfg]
2026-09-25 calibration cube 50mm size compensation
2026-09-25 calibration cube 50mm
2026-09-29 50x50 calibration cube
